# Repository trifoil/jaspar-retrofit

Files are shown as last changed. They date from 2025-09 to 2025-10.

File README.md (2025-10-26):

# jaspar-retrofit
Retrofit of Jaspar 1MVZ milling machine

## Components

| Quantity | Brand | Designation  |  Useful name  | Additional comments |
|:---|:---|:---|:-----|:-----|
|1| Schneider Electric | XB5AA25 |  Push button, Black |/|
|1| Schneider Electric | XB5AA15 |  Push button, White |/|
|1| Schneider Electric | XB5AA61 |  Push button, Blue |/|
|1| Schneider Electric | XB5AA55 |  Push button, Yellow |/|
|2| Schneider Electric | XB5AD33 | Selector switch | / |
|1| Schneider Electric | XB5PUSB3 |  Panel mounted USB 3.0 port | / |
|1| Schneider Electric | XB5AVB4 | Pilot light | / |

## Wiring 

### Operating principles

Once the main switch is turned on, the power is on for the computer, 24V alims and 

---

**Estop**

The E-stop has two contacts

* ZBE102 (red), Normally Closed, wired to a Mesa input     
* ZBE102 (red), Normally Closed, wired to the main safety relay     

When pressed, the circuit is open, as if there was no wire (that way if the estop wire is disconnected, the machine won't start):
* Software Estop is enabled
* The machine is on
* The relay is disabled, and the power contactors (X, Y, Z and Spindle) are open.
If the E-stop is disengaged, the circuit is closed and :
* Software Estop is disabled
* The machine is off
* The relay is enabled, and the power contactors (X, Y, Z and Spindle) are closed.

---

**Jog mode**

The MPG encoder is powered by 5V, linked to GND, and has 4 outputs but two are used : A+ and B+.

To override the normal operation of the machine one button is pressed, and enables the jog wheel while pressed.

The pin to enable jog is hm2_7i76e.0.7i76.0.0.input-20

Two selector buttons allow for selecting :

* The axis to move :
    * X
    * Y
    * Z
* The speed at which it is moving : 
    * X1
    * X10
    * X100

The card is in mode 2 to enable mpg inputs on these pins (sserial_port_0=20xxxxxx)

* The A+ signal is wired to hm2_7i76e.0.7i76.0.0.input-16
* The B+ signal is wired to hm2_7i76e.0.7i76.0.0.input-17

That way, the mpg input is readable on hm2_7i76e.0.7i76.0.0.enc0.count

For the axis selection : 

* hm2_7i76e.0.7i76.0.0.input-23
* hm2_7i76e.0.7i76.0.0.input-24
* if none is selected, Y is the axis to be selected

For the speed selection : 

* hm2_7i76e.0.7i76.0.0.input-21
* hm2_7i76e.0.7i76.0.0.input-22
* if none is selected, X10 is the axis to be selected

---

### Conventions

Convention for terminal blocks, where `X` is any number : 

| Designation  |  Useful name  |
|:---|:-----|
| 24v + | 24V+ |
| 24v gnd | 0V |
| 230v phase | P |
| 230v neutral | N |
| Coils | K`X` |
| Contact | K`X`.`X` |
| Switch | S |

### Mesa 7i76e jumpers

W2 and W3 are down, so the address of the card is 192.168.1.121 (default)

```sh
x@fedora:~$ ping 192.168.1.121
```

The answer should be : 
```txt
PING 192.168.1.121 (192.168.1.121) 56(84) bytes of data.
64 bytes from 192.168.1.121: icmp_seq=1 ttl=64 time=0.091 ms
64 bytes from 192.168.1.121: icmp_seq=2 ttl=64 time=0.109 ms
64 bytes from 192.168.1.121: icmp_seq=3 ttl=64 time=0.121 ms
```

### Mesa 7i76e wiring

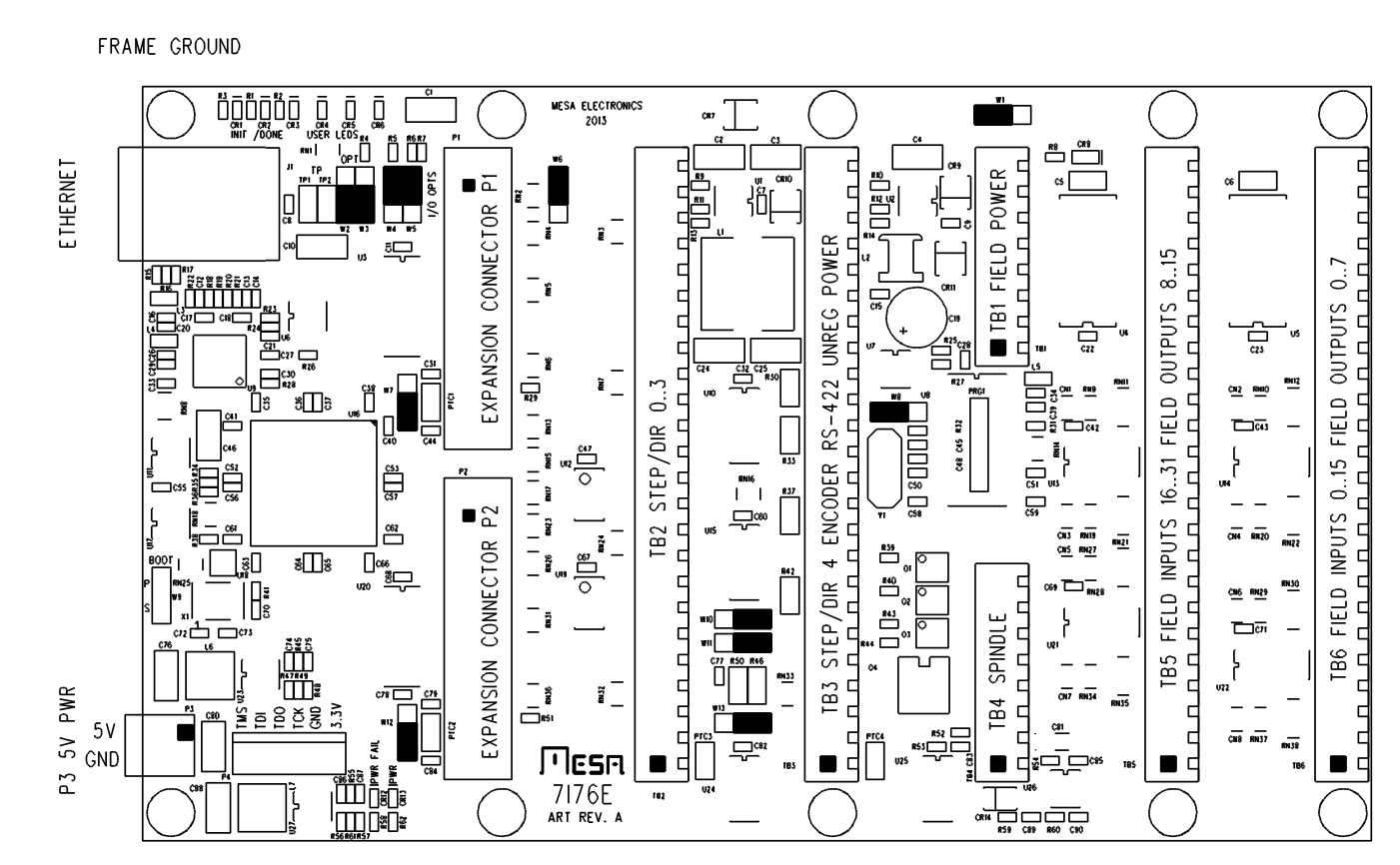
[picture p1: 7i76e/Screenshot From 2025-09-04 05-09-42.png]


Pins are numbered from bottom up.

0) **Power**

    | TB1 pin  |  Name   | Terminal block |
    |:---|:-----|:---|
    | 5 | VIN |  24V+  |     
    | 8 | GROUND |  0V  |     

    | TB3 pin  |  Name   | Terminal block |
    |:---|:-----|:---|
    | 22 | UNREG LOGIC PWR+ IN |  24V+  |     
    | 23 | GND |  0V  |    

1) **x Axis** 

    | TB2 pin  |  Name   |  Interface card pin  |
    |:---|:-----|:---|
    | 1 | GND |  /  |     
    | 2 |  STEP0-   | 41  |     
    | 3 |   STEP0+  |  43 |     
    | 4 |   DIR0-  |  37 |     
    | 5 |   DIR0+   | 39  |     
    | 6 |  +5VP   |  /  |     

2) **y Axis**

    | TB2 pin  |  Name   |  Interface card pin  |
    |:---|:-----|:---|
    | 7 | GND |  /  |     
    | 8 |  STEP1-   | 41  |     
    | 9 |   STEP1+  |  43 |     
    | 10 |   DIR1-  |  37 |     
    | 11 |   DIR1+   | 39  |     
    | 12 |  +5VP   |  /  |     

3) **z Axis**

    | TB2 pin  |  Name   |  Interface card pin  |
    |:---|:-----|:---|
    | 13 | GND |  /  |     
    | 14 |  STEP2-   | 41  |     
    | 15 |   STEP2+  |  43 |     
    | 16 |   DIR2-  |  37 |     
    | 17 |   DIR2+   | 39  |     
    | 18 |  +5VP   |  /  |     

4) **Spindle**

    | TB5 pin  |  Name   |  Relay coil  |
    |:---|:-----|:---|
    | 17 | OUTPUT8 |  C1  |     

5) **Jog MPG** (hm2_7i76e.0.7i76.0.0.enc0.count)

    | TB3 pin  |  Name   | MPG contact |
    |:---|:-----| :--- |
    | 9 | GND | GND |
    | 12 | +5VP | VCC |

    | TB5 pin  |  Name   | MPG contact |
    |:---|:-----| :--- |
    | 1 | INPUT16 | A+ |
    | / | / | A- |
    | 2 | INPUT17 | B+ |
    | / | / | B- |

6) **Jog enabling button**

    | TB5 pin  |  Name   | HAL name |
    |:---|:-----|:---|
    | 5 | INPUT20 | hm2_7i76e.0.7i76.0.0.input-20 |

7) **Speed selector button**

    | TB5 pin  |  Name   |  Position  |
    |:---|:-----|:---|
    | 6 | INPUT21 | X1 |
    | 7 | INPUT22 | X100 |

    If none is selected, the speed is X10

8) **Axis selector button**

    | TB5 pin  |  Name   |  Position  |
    |:---|:-----|:---|
    | 8 | INPUT23 | X |
    | 9 | INPUT24 | Z |

    If none is selected, the axis is Y

9) **Program start**

    | TB5 pin  |  Name   |  
    |:---|:-----|
    | 10 | INPUT25 | 

10) **Program pause**

    | TB5 pin  |  Name   |
    |:---|:-----|
    | 11 | INPUT26 |

11) **Estop**

    | TB5 pin  |  Name   |
    |:---|:-----|
    | 12 | INPUT27 |

12) **Coolant**

    | TB5 pin  |  Name   |
    |:---|:-----|
    | 13 | INPUT28 |

13) **Limit switches**

    | TB6 pin  |  Name   | Axis |
    |:---|:-----|:---|
    | 1 | INPUT0 | X |
    | 2 | INPUT1 | Y |
    | 3 | INPUT2 | Z |

14) **Homing sensor**

    | TB6 pin  |  Name   | Axis |
    |:---|:-----|:---|
    | 4 | INPUT3 | X |
    | 5 | INPUT4 | Y |
    | 6 | INPUT5 | Z |

15) **Z axis brake**

    | TB5 pin  |  Name   |
    |:---|:-----|
    | 18 | OUTPUT9 |

## Important notes 

In order to select the mode 2 of the mesa 7i76e board, this line 

```hal
loadrt hm2_eth board_ip="192.168.1.121" config="num_encoders=1 num_pwmgens=0 num_stepgens=5 sserial_port_0=00xxxxxx" 
```

has to be changed to this

```hal
loadrt hm2_eth board_ip="192.168.1.121" config="num_encoders=1 num_pwmgens=0 num_stepgens=5 sserial_port_0=20xxxxxx" 
```

The pc is connected with : 
* ip:192.168.1.3 
* gateway:192.168.1.254 
* mask: 255.255.255.0

## QTPYVCP interface

```sh
sudo apt update -y
sudo apt upgrade -y

sudo apt install curl -y
echo 'deb [arch=amd64] https://repository.qtpyvcp.com/apt stable main' | sudo tee /etc/apt/sources.list.d/kcjengr.list
curl -sS https://repository.qtpyvcp.com/repo/kcjengr.key | gpg --dearmor | sudo tee /etc/apt/trusted.gpg.d/kcjengr.gpg
gpg --keyserver keys.openpgp.org --recv-key 2DEC041F290DF85A
sudo apt update -y

sudo apt install python3-qtpyvcp -y
sudo apt install python3-probe-basic -y
sudo apt install python3-monokrom -y 
sudo apt install python3-turbonc -y

```

## Sources

https://www.qtpyvcp.com/index.html

## Notes

I have one homing inductive sensor per axis

I have two limit switches per axis (that trip the physical estop) 

I want my machine to have a homing performed when I switch it on.

Estop off -> machine enabled -> axis moving a bit in the opposite direction of the home -> axis moving back until the home proximity sensor trips -> axis are zeroed

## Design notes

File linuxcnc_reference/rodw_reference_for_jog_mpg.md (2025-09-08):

But back onto LinuxCNC, I promised I'd show document how I got an MPG running on the 7i76e. Lets start with the scale selector. I knew I need a 2 bit binary output but I've only ever made them in software before so I asked a friend what to get and he said to get one of these from Jaycar . That looked right to me so I grabbed one as I was close to one of their shops.

There were 3 outputs in the centre of the switch (A, B & C). We only need two of these so I picked A & B. But it really did my head in trying to work out how to use it in the absence of documentation. After a while with a multimeter I worked out which wire went where but I still could not work it out. Then I decided I needed to build a truth table showing the binary logic required:

 Pos   A B
  0:   0 0
  1:   0 1
  2:   1 0
  3:   1 1

And work out what wires were required to be live where ever there was a 1. My switch pinout said I needed to make pins 3, 4, 6 and 8 live so I tied them together with a yellow wire attached to +24v and an orange and green wire on the centre inputs going to the mux4 pins.

File Attachment:

File Attachment:

I made a bracket for the 100PPR encoder wheel from some scrap angle iron so it would not short out
File Attachment:

The wiring was pretty simple

I stole some 5 volt power from one of the stepper power pins.
Encode A connects to TB3.16
Encoder B connects to TB3.17

I did run into trouble until I found a post from PCW which said if you are using a separate 5V power supply like I am, you needed to tie the 24 volt and 5 volt pin Grounds together. Eg. Connect TB1.1 to TB2.23. But if you follow this wiring schematic , you won't need to do this

As the 7i76e has 2 encoder inputs, I figured I'd use separate encoders for the X & Y axis.

Some of the examples I had seen used the -not signal from an unused input for the encoder enable inut but this looked a bit dodgy to me. Why not simply OR the 2 encoder input pins together and use the output from that as the enable signal? By doing that , the encode will be disabled when the scale switch is at position 0 and enabled at any of the scale settings. Nice and clean!

Here is what the HAL file looks like:

```hal
# Metric units used
loadrt hm2_eth board_ip="10.10.10.10" config="firmware=hm2/7i76/7i76e.BIT num_encoders=1 num_pwmgens=0 num_stepgens=5  sserial_port_0=2xxxx" 

loadrt mux4 count=1
addf mux4.0 servo-thread
loadrt or2 count=4
addf or2.3  servo-thread

setp axis.x.jog-vel-mode 0
net x-jog-counter <=  hm2_7i76e.0.7i76.0.0.enc0.count
net x-jog-counter => axis.x.jog-counts
net mux-in1 or2.3.in0 <= hm2_7i76e.0.7i76.0.0.input-22 => mux4.0.sel0
net mux-in2 or2.3.in1 <= hm2_7i76e.0.7i76.0.0.input-21 => mux4.0.sel1
net x-jog-enable <= or2.3.out
net x-jog-enable => axis.x.jog-enable
setp mux4.0.in0 0.0
setp mux4.0.in1 1.0
setp mux4.0.in2 0.1
setp mux4.0.in3 0.01
net x-jog-scale mux4.0.out => axis.x.jog-scale
```

This is set up for a metric machine and the scale is 1mm, 0.1mm and 0.01mm. If you find the scale is reversed, it is becasue the pins are mapped in the reverse order. (eg low order pin connected to high order bit). If this happens to you, just edit the pins in this code.
```hal
net mux-in1 or2.3.in0 <= hm2_7i76e.0.7i76.0.0.input-22 => mux4.0.sel0
net mux-in2 or2.3.in1 <= hm2_7i76e.0.7i76.0.0.input-21 => mux4.0.sel1
```

Remember to change this line based on your config. I had already used a few or2's
```hal
loadrt or2 count=4
```
Well, thats about it for now. The shopping list is becoming very short.
1. 9 core shielded wire for the connection to the plasma power supply now the connector is to hand
2. A 3 stage air filter including a desiccant drier stage I've had my eye on.
3. About 10 metres of 100 x 100 x 5mm SHS for the frame and some other sundry steel.

The main things I have to do in HAL are:
1. All the THC stuff
2. Sort out my stepper drives so they are working on the correct axis
3. Implement Gantry Joint Axis .
4. Get my warning lights working the way I want them to and I'll need some help on that one.

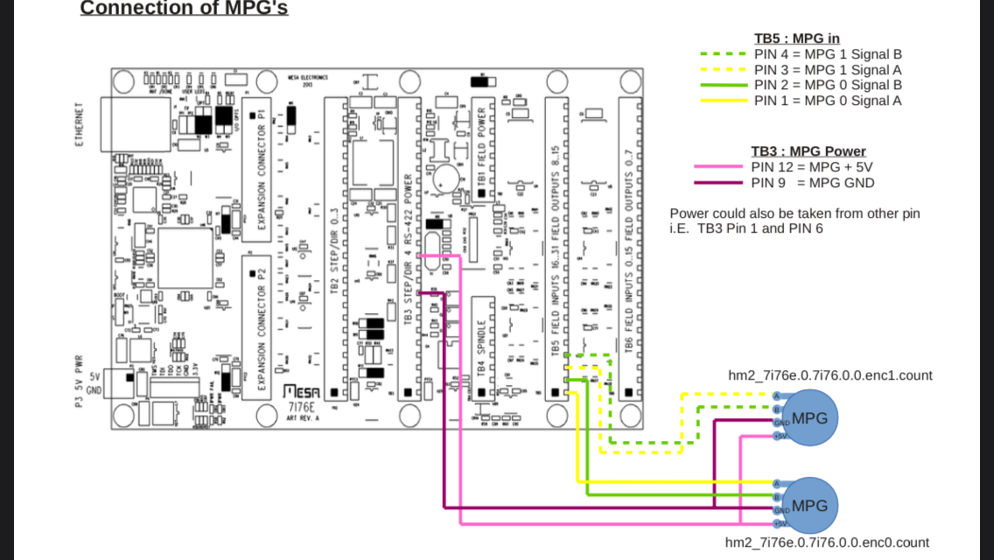
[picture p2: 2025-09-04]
Pasted image (2).png

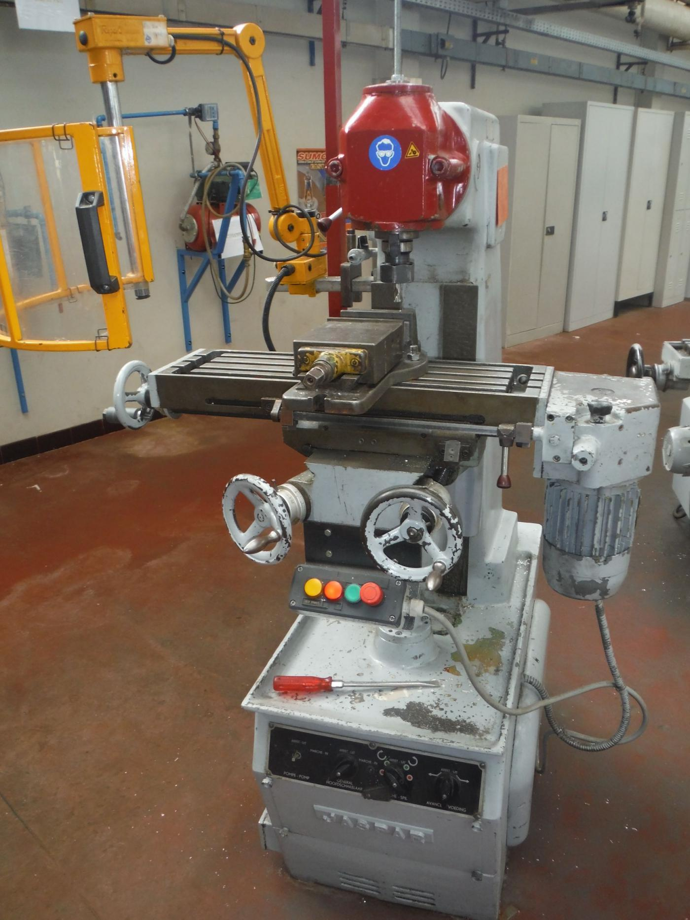
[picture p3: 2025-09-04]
Pasted image.png

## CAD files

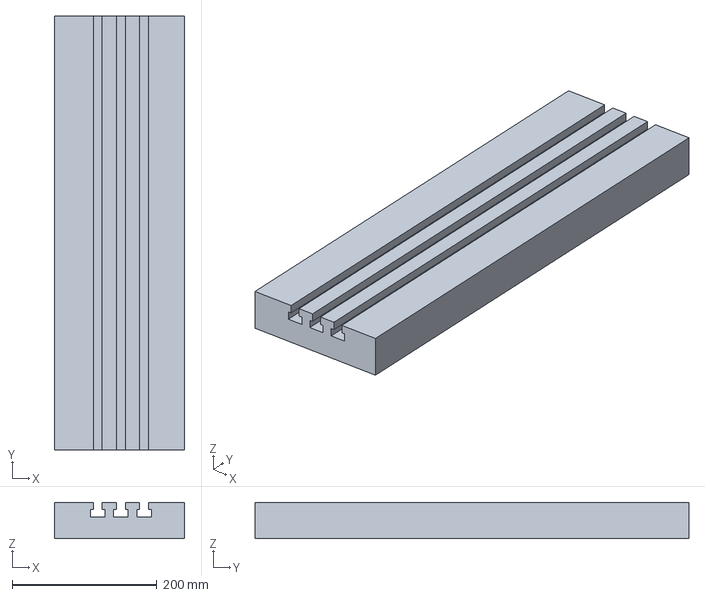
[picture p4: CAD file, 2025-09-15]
3d_models/JASPAR_6_0_0_table.FCStd
180.0 x 600.0 x 50.0 mm

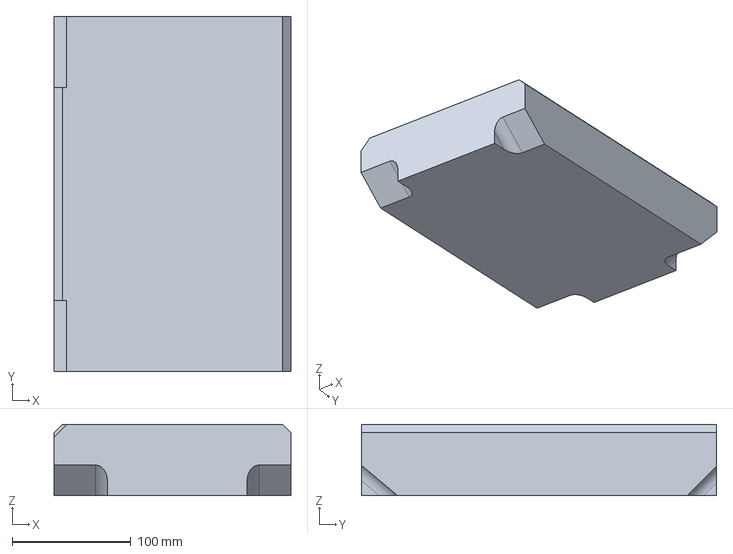
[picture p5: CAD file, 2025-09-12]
3d_models/JASPAR_5_0_0_mid.FCStd
200.0 x 300.0 x 60.0 mm

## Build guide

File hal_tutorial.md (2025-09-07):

# HAL

Hal stands for ```hardware abstraction layer```

Assembles blocks to work together

At first it was only for hardware devices

## Principles

* Any system consists of interconnected components.
* The machine builder must select, mount and wire these pieces together to make a complete system.

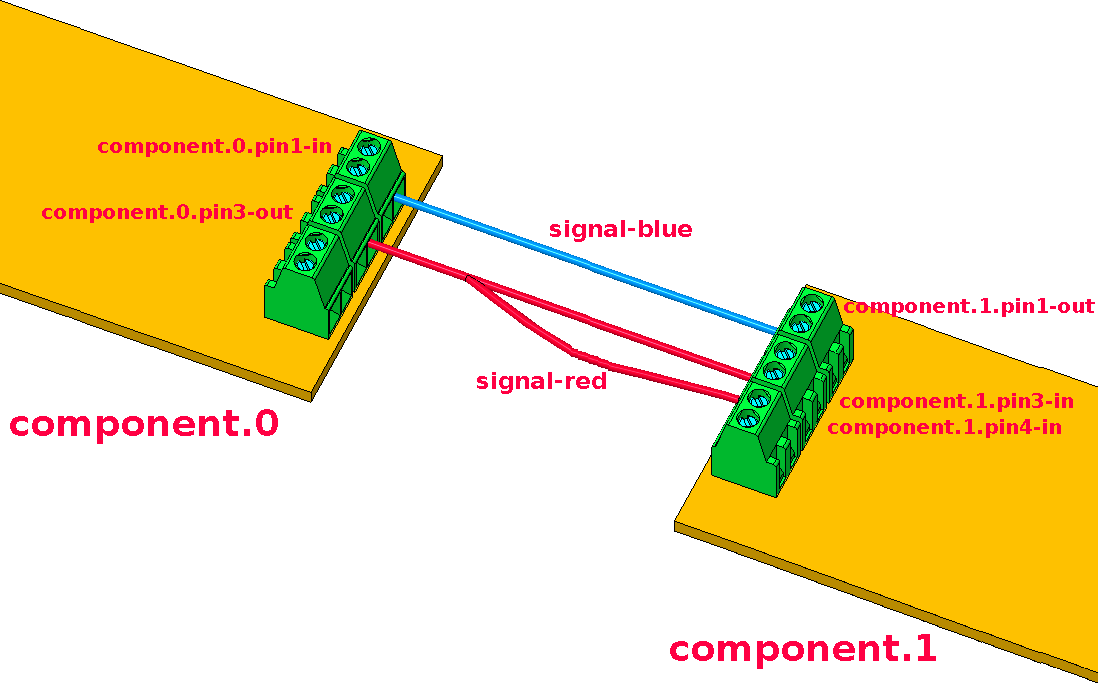
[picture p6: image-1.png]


translates to :

```txt
net signal-blue    component.0.pin1-in      component.1.pin1-out
net signal-red     component.0.pin3-out     component.1.pin3-in     component.1.pin4-in
```

### Part selection

* The machine builder treats each individual part as black boxes.
* In the HAL world, the integrator must decide what HAL components are needed. 
* Usually every interface card will require a driver. 
* Additional components may be needed for software generation of step pulses, PLC functionality, and a wide variety of other tasks.

### Interconnecting

* When using HAL, components are interconnected by signals. 
* The designer must decide which signals are needed, and what they should connect.

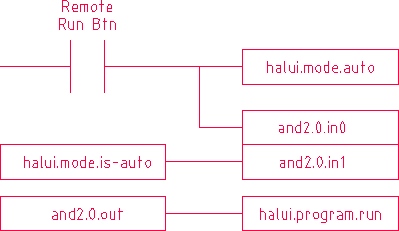
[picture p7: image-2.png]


# Estop

```hal
# --- Load the necessary components ---
# Load the driver for your I/O card (7i96 in this example)
loadrt hm2_eth board_ip="192.168.1.121" config="num_encoders=0 num_stepgens=5"
loadrt threads name1=servo-thread period1=1000000 # 1ms thread

# Load a simple logic component (NOT gate)
loadrt not count=1

# --- Wire the physical input to the HAL ---
# Connect the physical pin "INPUT18" to a HAL pin named "estop_physical"
net estop-physical-in hm2_7i96.0.7i96.gpio.055.in-18 => not.0.in

# --- Apply the necessary logic ---
# The physical input is ACTIVE LOW (FALSE when pressed).
# We need to INVERT it to get an ESTOP signal that is TRUE when active.
net estop-active not.0.out => iocontrol.0.emc-enable-in

# --- Add the components to a thread so they run ---
addf not.0 servo-thread
addf hm2_7i96.0.read servo-thread
addf hm2_7i96.0.write servo-thread
```

How it works:

* The physical E-Stop button is wired to INPUT18.

* The hm2_7i96 driver reads this pin and sets the value of its HAL pin hm2_7i96.0.7i96.gpio.055.in-18.

* The net command connects this physical pin to the input of a not component.

* The not component inverts the signal:

    * E-Stop NOT pressed (circuit closed): in-18 is TRUE -> not.out is FALSE

    * E-Stop IS pressed (circuit open): in-18 is FALSE -> not.out is TRUE

* This inverted signal (estop-active) is then connected to iocontrol.0.emc-enable-in. This pin expects TRUE to enable the machine and FALSE to disable it. Our logic now correctly disables the machine when the E-Stop is pressed.

## NOT

Right now your E-Stop is wired as normally closed (NC), so you’re inverting the signal with not.0.
If you’re changing it to normally open (NO) — meaning 1 = pressed / fault, 0 = OK — then you no longer need the not component.

Here’s how you can modify your HAL file:

Remove these lines:

loadrt not
addf not.0 servo-thread
net estop-in     => not.0.in
net estop-fault  <= not.0.out
net estop-fault    => iocontrol.0.emc-enable-in

Replace with a direct connection:
# --- Physical E-stop on INPUT18 ---
# Normally open: 0 = OK, 1 = E-stop pressed

net estop-in    <=  hm2_7i76e.0.7i76.0.0.input-18
net estop-in    =>  iocontrol.0.emc-enable-in
This way, the signal from your Mesa input goes directly to LinuxCNC’s iocontrol.0.emc-enable-in, no inversion needed.

⚠️ Before running the machine, test with halmeter or halscope:

E-Stop released → signal = 0 (OK)

E-Stop pressed → signal = 1 (Triggers E-Stop)

Do you also want me to adjust comments in the HAL file so it’s clear it’s now NO wiring instead of NC?

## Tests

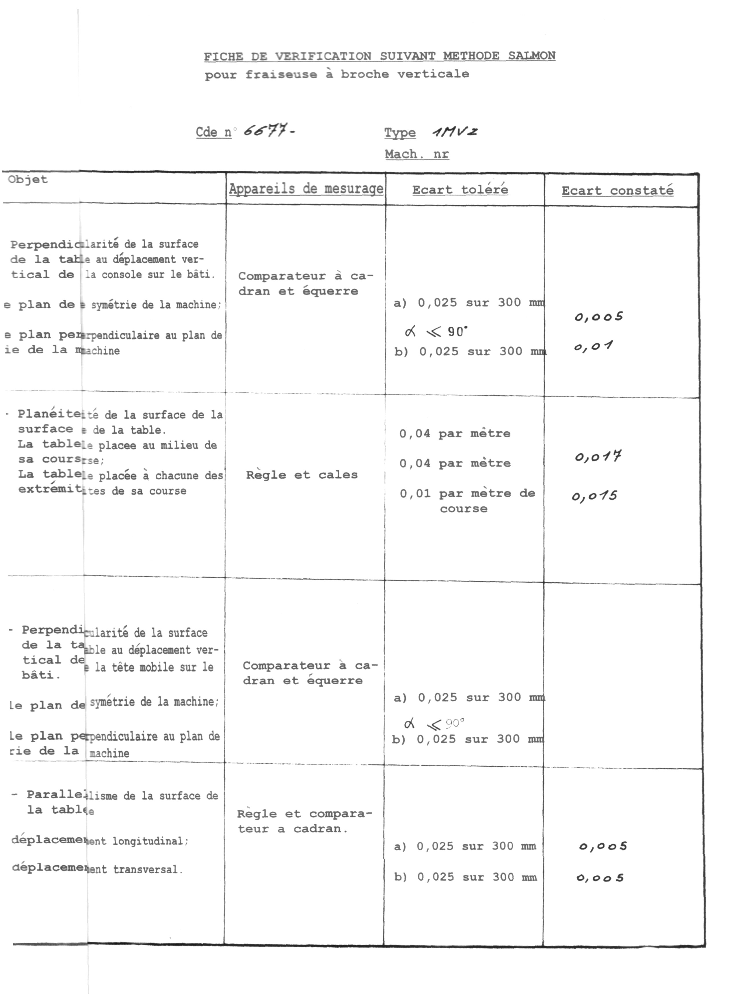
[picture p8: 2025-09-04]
Jaspar 1MVZ Handleiding-v2/1MVZ-Verificatie-1b.jpg

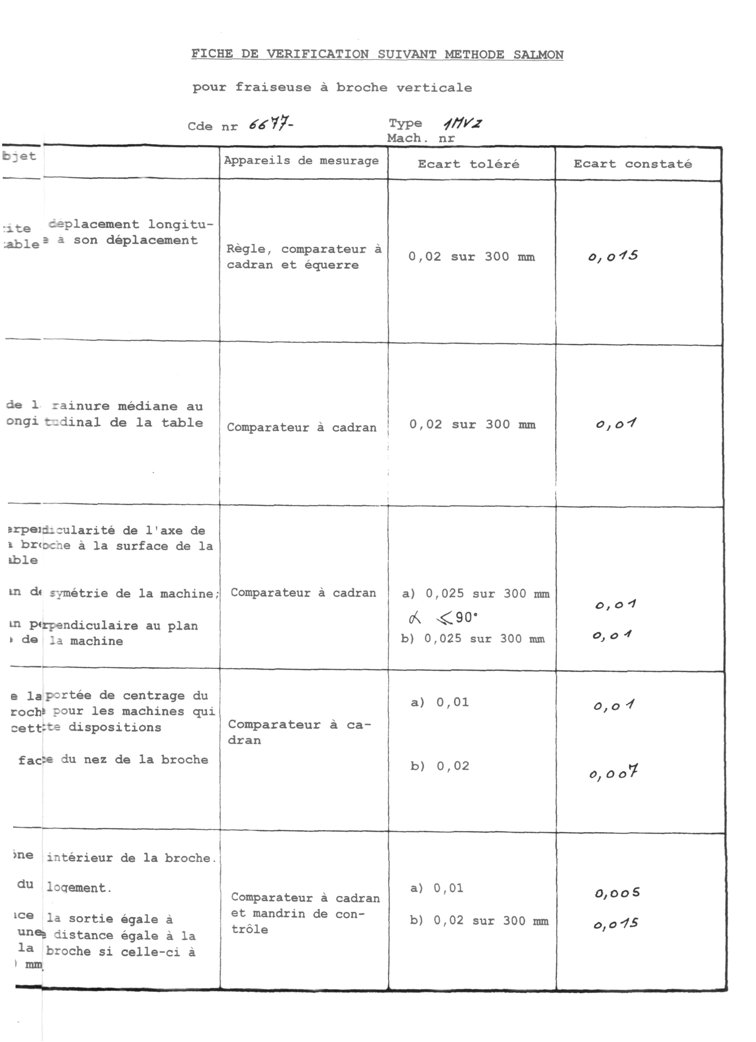
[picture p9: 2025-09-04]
Jaspar 1MVZ Handleiding-v2/1MVZ-Verificatie-2b.jpg

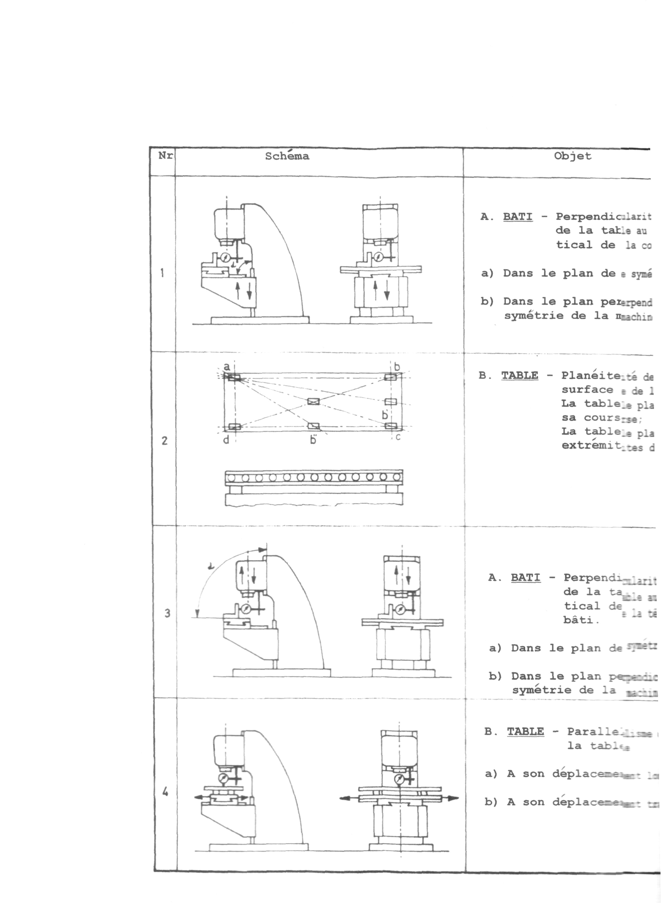
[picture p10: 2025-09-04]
Jaspar 1MVZ Handleiding-v2/1MVZ-Verificatie-1a.jpg

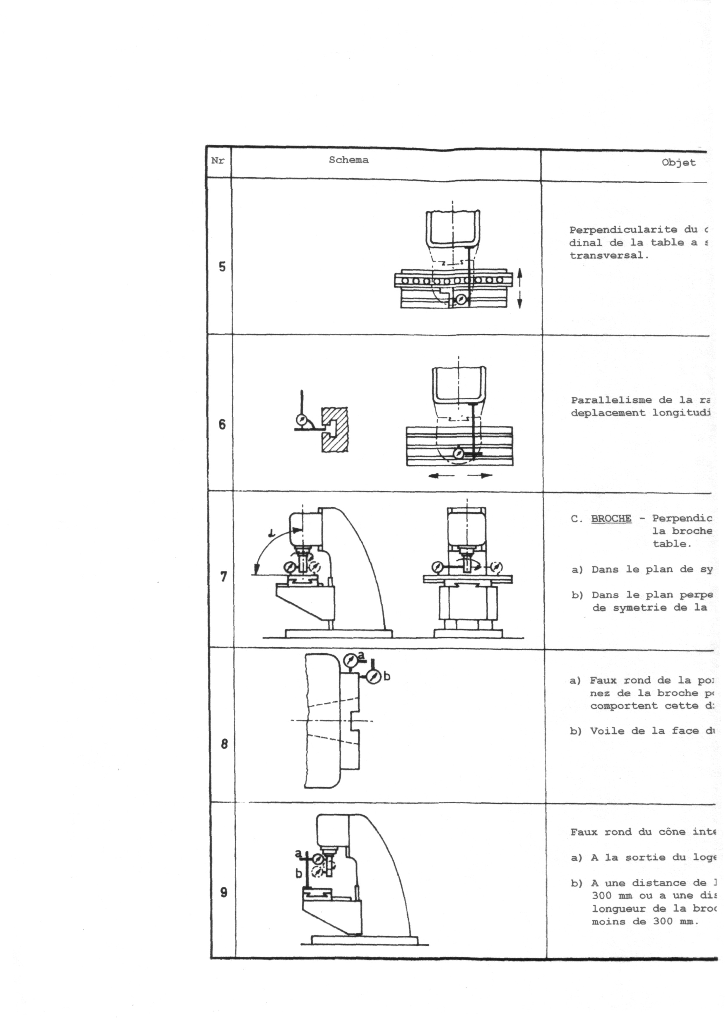
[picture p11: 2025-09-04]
Jaspar 1MVZ Handleiding-v2/1MVZ-Verificatie-2a.jpg

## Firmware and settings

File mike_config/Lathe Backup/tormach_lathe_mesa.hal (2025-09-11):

# Tormach Lathe Hal file for Mesa 5i25 and 7i92

# load RT components
loadrt trivkins
loadusr -W hwmon $INI_FILE_NAME
loadrt [EMCMOT]EMCMOT servo_period_nsec=[EMCMOT]SERVO_PERIOD num_joints=[TRAJ]AXES num_dio=64
loadrt hostmot2
loadrt [HOSTMOT2]DRIVER [HOSTMOT2]DRIVER_PARAMS
loadrt estop_latch
loadrt tormachltc
#loadrt near
loadrt gearchange count=1
loadrt not names=prog-not-idle
loadrt machineokdb names=machine-ok-db
loadrt and2 names=stepper-drive-trip,probe-enable-input 
loadrt ilowpass count=2
loadrt tormachcolletcontrol

# Load the mux4 and two or2's for mpgs
loadrt or2 names=enable-limits,or-mux-in0,or-mux-in1
loadrt mux4 names=mux-axis-scale
loadusr -Wn usbio usbio.py -n usbio





# as per Peter Wallace to reduce encoder errors from noise
# use the 'raw' interface to set the encoder filter higher to ignore more noise
# this sets how long an encoder signal needs to be stable to be accepted
# register 0x3400 is QfilterRate decimal 13312
# count rate is ClockLow/(QfilterRate + 2)
# ClockLow is 33 MHz
# setting the filter to 38 (decimal) will allow the encoder to function well past 100 kHz
# lathe encoder is 1200 pulses per rev, 3000 RPM is 60 kHz
#
# TODO: FIX ME!!!!!
#setp hm2_[HOSTMOT2](BOARD).0.raw.write_address 13312
#setp hm2_[HOSTMOT2](BOARD).0.raw.write_data [SPINDLE]ENCODER_FILTER
#setp hm2_[HOSTMOT2](BOARD).0.raw.write_strobe TRUE

# stabilizes spindle RPM display
loadrt lowpass
setp lowpass.0.gain 0.01

# debounce - coolant relay switching noise hammers estop input
loadrt debounce cfg=1,3

# lut5.0 looks to be limit switch related
# lut5.1 handles collet closer control
loadrt lut5 count=2

# probe active high or low
loadrt xor2 names=probe-active-hi-lo




# used to decode the signal from the lathe control board that encodes
# the door and limit switches as a frequency
#loadrt freq2pin personality=0x0004
#setp freq2pin.0.freq-width 200
#setp freq2pin.0.input 0
#setp freq2pin.0.stability-count 25
#setp freq2pin.0.stability-width 20
#setp freq2pin.0.freq-table-00 1800
#setp freq2pin.0.freq-table-01 2000
#setp freq2pin.0.freq-table-02 2200
#setp freq2pin.0.freq-table-03 2400
#setp freq2pin.0.freq-table-04 2600
#setp freq2pin.0.freq-table-05 2800
#setp freq2pin.0.freq-table-06 3000
#setp freq2pin.0.freq-table-07 3200
#setp freq2pin.0.freq-table-08 3400
#setp freq2pin.0.freq-table-09 3600
#setp freq2pin.0.freq-table-10 3800
#setp freq2pin.0.freq-table-11 4000
#setp freq2pin.0.freq-table-12 4200
#setp freq2pin.0.freq-table-13 4400
#setp freq2pin.0.freq-table-14 4600
#setp freq2pin.0.freq-table-15 4800

#############################################################################
# servo thread
#
# mesa card .read should be the first thing added to the servo-thread
# where .write should be the last thing added. that way everything
# gets the freshest data from .read and .write sets all the new output data
#
addf hm2_[HOSTMOT2](BOARD).0.read servo-thread

#addf freq2pin.0 servo-thread


addf lut5.0 servo-thread
addf lut5.1 servo-thread
addf debounce.0 servo-thread
addf debounce.1 servo-thread
addf probe-active-hi-lo servo-thread
addf probe-enable-input servo-thread
addf enable-limits servo-thread
addf stepper-drive-trip servo-thread

# Add the components to the servo-thread
addf mux-axis-scale servo-thread
addf or-mux-in0     servo-thread
addf or-mux-in1     servo-thread
addf ilowpass.0     servo-thread
addf ilowpass.1     servo-thread




########################################################################
# noise debounce for estop
# debounce.0 no longer used but left installed for the time being
# temporarily bump from 150 ms to 850 ms to debug seemingly random e-stops
#setp debounce.0.delay 850
###### estop debounce

addf machine-ok-db servo-thread
setp machine-ok-db.delay 850

# limit and door switches and probe/accessory input
setp debounce.1.delay 10

addf lowpass.0 servo-thread

# always needed
addf motion-command-handler servo-thread
addf motion-controller servo-thread

addf estop-latch.0 servo-thread

# used by spindle speed
addf gearchange.0 servo-thread
#addf near.0 servo-thread

addf tormachltc.0 servo-thread

addf prog-not-idle servo-thread

addf tormachcolletcontrol.0 servo-thread

# .write should be last after new outputs are computed
# in servo-thread

addf hm2_[HOSTMOT2](BOARD).0.write servo-thread



###############################################################
# 5i25 watchdog timeout
# 10 milliseconds (~10 times the servo loop period)
setp hm2_[HOSTMOT2](BOARD).0.watchdog.timeout_ns 10000000


###############################################################
# 5i25
# Configuration pin-out:

### hm2_[HOSTMOT2](BOARD).0.gpio.016.in Encoder-phase-A
### hm2_[HOSTMOT2](BOARD).0.gpio.015.in Encoder-phase-B
### hm2_[HOSTMOT2](BOARD).0.gpio.014.in_not Encoder-phase-Z

#
#    IO Connections For 7i76

#	TB6 Pin    	INPUT Pins
#	1    		0-INPUT		Stepper Drive Trip
#    	2		1-INPUT		Stepper Drive Trip
#    	3		2-INPUT       
#    	4		3-INPUT 	Door Switch      
#    	5		4-INPUT		Z Limit Switch       
#    	6		5-INPUT		X Limit Switch       
#    	7		6-INPUT      
#    	8		7-INPUT		Probe Input      
#    	9		8-INPUT 
#	10		9-INPUT		
      
#    TB6 Pin 		Output Pins         
#    	17		0-Output	Spindle Forward Relay       
#    	18		1-Output	Spindle Reverse Relay       
#    	19		2-Output	Flood Coolant
#    	20		3-Output      	Mist Coolant
#    	21		4-Output  
#    	22		5-Output    	VFD Enable Relay 
#    	23		6-Output       
#    	24		7-Output	STOP Output Pin   


#    TB5 Pin 		Output Pins  
#    	17		8-Output    
#    	18		9-Output
#    	19		10-Output
#    	20		11-Output
#    	21		12-Output
#    	22		13-Output
#   	23	 	14-Output 	Enable Limits Output Pin
#	24		15-Output


# 	TB2		Signal Pins
#	1		GND
#	2		Step0-
#	3		Step0+
#	4		Dir0-
#	5		Dir0+
#	6		+5V
#	7		GND
#	8		Step1-
#	9		Step1+
#	10		Dir1-
#	11		Dir1+
#	12		+5V
#	13		GND
#	14		Step2-
#	15		Step2+
#	16		Dir2-
#	17		Dir2+
#	18		+5V
#	19		GND
#	20		Step3-
#	21		Step3+
#	22		Dir3-
#	23		Dir3+
#	24		+5V


# 	TB3		Signal Pins
#	1		GND
#	2		Step4-
#	3		Step4+
#	4		Dir4-
#	5		Dir4+
#	6		+5V
#	7		ENCA+
#	8		ENCA-
#	9		GND
#	10		ENCB+
#	11		ENCB-
#	12		GND
#	13		+5V
#	14		IDX+
#	15		IDX-
#	16		
#	17		
#	18		
#	19		
#	20		+5V
#	21		+5V
#	22		+5V
#	23		GND
#	24		GND

#############################################################################
# Load Comp for Arduino Mega Controlled I/0 copy to folder below
# sudo cp arduino-connector.py /home/operator/v2.9.2/bin/arduino-connector

#loadusr arduino-connector 

#############################################################################



########################################################################
# DPLL configuration
#setp hm2_[HOSTMOT2](BOARD).0.dpll.01.timer-us [HOSTMOT2](DPLL_TIMER_US)

# default is -1 which means don't use the DPLL timer and simply sample on read()
# set to 1 for Ethernet boards to use DPLL timer 1 and sample 100 micro seconds
# before the nominal servo thread read() time
#setp hm2_[HOSTMOT2](BOARD).0.stepgen.timer-number  [HOSTMOT2](DPLL_TIMER_NUMBER)
#setp hm2_[HOSTMOT2](BOARD).0.encoder.timer-number  [HOSTMOT2](DPLL_TIMER_NUMBER)

###############################################################
# Spindle speed controlled by frequency
#
# LinuxCNC (rpm) => gearchange (pulse-freq) => stepgen (step & dir) => spindle
#

setp gearchange.0.min1 [SPINDLE]LO_RANGE_MIN
setp gearchange.0.max1 [SPINDLE]LO_RANGE_MAX
setp gearchange.0.min2 [SPINDLE]HI_RANGE_MIN
setp gearchange.0.max2 [SPINDLE]HI_RANGE_MAX
setp gearchange.0.scale2 [SPINDLE]HI_RANGE_SCALE
setp gearchange.0.sel 1
net spindle-range            gearchange.0.sel
net spindle-range-alarm      gearchange.0.alarm

# direction not controlled via gearchanger, so reverse isn't set
# and the dir-in and dir-out pins aren't linked

net spindle-speed-raw motion.spindle-speed-out gearchange.0.speed-in
net spindle-speed gearchange.0.speed-out hm2_[HOSTMOT2](BOARD).0.stepgen.01.velocity-cmd

# type 1 velocity control mode
setp hm2_[HOSTMOT2](BOARD).0.stepgen.01.control-type 1

# step/dir
# type 2 quadrature output for 50% duty cycle
setp hm2_[HOSTMOT2](BOARD).0.stepgen.01.step_type 2

# position = counts / position_scale
# this scales the input RPM to the output frequency
# fast spindle pulley 1000 Hz -> 1000 RPM
setp hm2_[HOSTMOT2](BOARD).0.stepgen.01.position-scale [SPINDLE]LO_SCALE

# no limit on acceleration
setp hm2_[HOSTMOT2](BOARD).0.stepgen.01.maxaccel 0

# for lathe 5000 Hz/RPM max
# 000 Hz maximum frequency, position units / second
setp hm2_[HOSTMOT2](BOARD).0.stepgen.01.maxvel 2000

# stepspace in nanoseconds
setp hm2_[HOSTMOT2](BOARD).0.stepgen.01.stepspace 0

# steplen 10 Micro Seconds
setp hm2_[HOSTMOT2](BOARD).0.stepgen.01.steplen 10000

# Spindle run assigned in the the POSTGUI_HALFILE
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

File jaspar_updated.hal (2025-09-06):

# Jaspar 1MVZ Milling Machine HAL Configuration - Updated
# Using Mesa 7i76e Ethernet card
# Based on current PNCconf structure with Jaspar customizations

# Generated by PNCconf at Sat Sep  6 04:06:15 2025
# Using LinuxCNC version:  Master (2.9)

loadrt [KINS]KINEMATICS
loadrt [EMCMOT]EMCMOT servo_period_nsec=[EMCMOT]SERVO_PERIOD num_joints=[KINS]JOINTS
loadrt hostmot2
loadrt hm2_eth board_ip="192.168.1.121" config="num_encoders=1 num_pwmgens=0 num_stepgens=3 sserial_port_0=00xxxxxx" 
setp    hm2_7i76e.0.watchdog.timeout_ns 5000000

# Jaspar custom components
loadrt pid names=pid.x,pid.y,pid.z
loadrt encoder names=mpg-encoder
loadrt mux4 names=mpg-mux
loadrt scale names=mpg-scale

addf hm2_7i76e.0.read          servo-thread
addf motion-command-handler   servo-thread
addf motion-controller        servo-thread
addf pid.x.do-pid-calcs       servo-thread
addf pid.y.do-pid-calcs       servo-thread
addf pid.z.do-pid-calcs       servo-thread
# Jaspar custom thread additions
addf mpg-encoder               servo-thread
addf mpg-mux                   servo-thread
addf mpg-scale                 servo-thread
addf hm2_7i76e.0.write         servo-thread
setp hm2_7i76e.0.dpll.01.timer-us -50
setp hm2_7i76e.0.stepgen.timer-number 1

# external output signals
# external input signals

#*******************
#  AXIS X JOINT 0
#*******************

setp   pid.x.Pgain     [JOINT_0]P
setp   pid.x.Igain     [JOINT_0]I
setp   pid.x.Dgain     [JOINT_0]D
setp   pid.x.bias      [JOINT_0]BIAS
setp   pid.x.FF0       [JOINT_0]FF0
setp   pid.x.FF1       [JOINT_0]FF1
setp   pid.x.FF2       [JOINT_0]FF2
setp   pid.x.deadband  [JOINT_0]DEADBAND
setp   pid.x.maxoutput [JOINT_0]MAX_OUTPUT
setp   pid.x.error-previous-target true
setp   pid.x.maxerror 0.012700

net x-index-enable  =>  pid.x.index-enable
net x-enable        =>  pid.x.enable
net x-pos-cmd       =>  pid.x.command
net x-pos-fb        =>  pid.x.feedback
net x-output        <=  pid.x.output

# Step Gen signals/setup
setp   hm2_7i76e.0.stepgen.00.dirsetup        [JOINT_0]DIRSETUP
setp   hm2_7i76e.0.stepgen.00.dirhold         [JOINT_0]DIRHOLD
setp   hm2_7i76e.0.stepgen.00.steplen         [JOINT_0]STEPLEN
setp   hm2_7i76e.0.stepgen.00.stepspace       [JOINT_0]STEPSPACE
setp   hm2_7i76e.0.stepgen.00.position-scale  [JOINT_0]STEP_SCALE
setp   hm2_7i76e.0.stepgen.00.step_type        0
setp   hm2_7i76e.0.stepgen.00.control-type     1
setp   hm2_7i76e.0.stepgen.00.maxaccel         [JOINT_0]STEPGEN_MAXACCEL
setp   hm2_7i76e.0.stepgen.00.maxvel           [JOINT_0]STEPGEN_MAXVEL

# ---closedloop stepper signals---
net x-pos-cmd    <= joint.0.motor-pos-cmd
net x-vel-cmd    <= joint.0.vel-cmd
net x-output     => hm2_7i76e.0.stepgen.00.velocity-cmd
net x-pos-fb     <= hm2_7i76e.0.stepgen.00.position-fb
net x-pos-fb     => joint.0.motor-pos-fb
net x-enable     <= joint.0.amp-enable-out
net x-enable     => hm2_7i76e.0.stepgen.00.enable

# ---setup home / limit switch signals---
net x-home-sw     =>  joint.0.home-sw-in
net x-neg-limit     =>  joint.0.neg-lim-sw-in
net x-pos-limit     =>  joint.0.pos-lim-sw-in

#*******************
#  AXIS Y JOINT 1
#*******************

setp   pid.y.Pgain     [JOINT_1]P
setp   pid.y.Igain     [JOINT_1]I
setp   pid.y.Dgain     [JOINT_1]D
setp   pid.y.bias      [JOINT_1]BIAS
setp   pid.y.FF0       [JOINT_1]FF0
setp   pid.y.FF1       [JOINT_1]FF1
setp   pid.y.FF2       [JOINT_1]FF2
setp   pid.y.deadband  [JOINT_1]DEADBAND
setp   pid.y.maxoutput [JOINT_1]MAX_OUTPUT
setp   pid.y.error-previous-target true
setp   pid.y.maxerror 0.012700

net y-index-enable  =>  pid.y.index-enable
net y-enable        =>  pid.y.enable
net y-pos-cmd       =>  pid.y.command
net y-pos-fb        =>  pid.y.feedback
net y-output        <=  pid.y.output

# Step Gen signals/setup
setp   hm2_7i76e.0.stepgen.01.dirsetup        [JOINT_1]DIRSETUP
setp   hm2_7i76e.0.stepgen.01.dirhold         [JOINT_1]DIRHOLD
setp   hm2_7i76e.0.stepgen.01.steplen         [JOINT_1]STEPLEN
setp   hm2_7i76e.0.stepgen.01.stepspace       [JOINT_1]STEPSPACE
setp   hm2_7i76e.0.stepgen.01.position-scale  [JOINT_1]STEP_SCALE
setp   hm2_7i76e.0.stepgen.01.step_type        0
setp   hm2_7i76e.0.stepgen.01.control-type     1
setp   hm2_7i76e.0.stepgen.01.maxaccel         [JOINT_1]STEPGEN_MAXACCEL
setp   hm2_7i76e.0.stepgen.01.maxvel           [JOINT_1]STEPGEN_MAXVEL

# ---closedloop stepper signals---
net y-pos-cmd    <= joint.1.motor-pos-cmd
net y-vel-cmd    <= joint.1.vel-cmd
net y-output     => hm2_7i76e.0.stepgen.01.velocity-cmd
net y-pos-fb     <= hm2_7i76e.0.stepgen.01.position-fb
net y-pos-fb     => joint.1.motor-pos-fb
net y-enable     <= joint.1.amp-enable-out
net y-enable     => hm2_7i76e.0.stepgen.01.enable

# ---setup home / limit switch signals---
net y-home-sw     =>  joint.1.home-sw-in
net y-neg-limit     =>  joint.1.neg-lim-sw-in
net y-pos-limit     =>  joint.1.pos-lim-sw-in

#*******************
#  AXIS Z JOINT 2
#*******************

setp   pid.z.Pgain     [JOINT_2]P
setp   pid.z.Igain     [JOINT_2]I
setp   pid.z.Dgain     [JOINT_2]D
setp   pid.z.bias      [JOINT_2]BIAS
setp   pid.z.FF0       [JOINT_2]FF0
setp   pid.z.FF1       [JOINT_2]FF1
setp   pid.z.FF2       [JOINT_2]FF2
setp   pid.z.deadband  [JOINT_2]DEADBAND
setp   pid.z.maxoutput [JOINT_2]MAX_OUTPUT
setp   pid.z.error-previous-target true
setp   pid.z.maxerror 0.012700

net z-index-enable  =>  pid.z.index-enable
net z-enable        =>  pid.z.enable
net z-pos-cmd       =>  pid.z.command
net z-pos-fb        =>  pid.z.feedback
net z-output        <=  pid.z.output

# Step Gen signals/setup
setp   hm2_7i76e.0.stepgen.02.dirsetup        [JOINT_2]DIRSETUP
setp   hm2_7i76e.0.stepgen.02.dirhold         [JOINT_2]DIRHOLD
setp   hm2_7i76e.0.stepgen.02.steplen         [JOINT_2]STEPLEN
setp   hm2_7i76e.0.stepgen.02.stepspace       [JOINT_2]STEPSPACE
setp   hm2_7i76e.0.stepgen.02.position-scale  [JOINT_2]STEP_SCALE
setp   hm2_7i76e.0.stepgen.02.step_type        0
setp   hm2_7i76e.0.stepgen.02.control-type     1
setp   hm2_7i76e.0.stepgen.02.maxaccel         [JOINT_2]STEPGEN_MAXACCEL
setp   hm2_7i76e.0.stepgen.02.maxvel           [JOINT_2]STEPGEN_MAXVEL

# ---closedloop stepper signals---
net z-pos-cmd    <= joint.2.motor-pos-cmd
net z-vel-cmd    <= joint.2.vel-cmd
net z-output     => hm2_7i76e.0.stepgen.02.velocity-cmd
net z-pos-fb     <= hm2_7i76e.0.stepgen.02.position-fb
net z-pos-fb     => joint.2.motor-pos-fb
net z-enable     <= joint.2.amp-enable-out
net z-enable     => hm2_7i76e.0.stepgen.02.enable

# ---setup home / limit switch signals---
net z-home-sw     =>  joint.2.home-sw-in
net z-neg-limit     =>  joint.2.neg-lim-sw-in
net z-pos-limit     =>  joint.2.pos-lim-sw-in

#*******************
#  SPINDLE CONTROL - Jaspar custom
#*******************
net spindle-on    => hm2_7i76e.0.7i76.0.0.output-08
net spindle-cw    => hm2_7i76e.0.7i76.0.0.output-09
net spindle-on    <= spindle.0.on
net spindle-cw    <= spindle.0.forward
net spindle-ccw   <= spindle.0.reverse

#*******************
#  MPG HANDWHEEL - Jaspar custom
#*******************
# MPG encoder configuration
setp mpg-encoder.position-scale 4
setp mpg-encoder.x4-mode 0

# MPG encoder connections
net mpg-a    <= hm2_7i76e.0.7i76.0.0.input-16
net mpg-b    <= hm2_7i76e.0.7i76.0.0.input-17
net mpg-a    => mpg-encoder.phase-A
net mpg-b    => mpg-encoder.phase-B

# MPG axis selection
net mpg-axis-x   <= hm2_7i76e.0.7i76.0.0.input-21
net mpg-axis-z   <= hm2_7i76e.0.7i76.0.0.input-22

# MPG scale selection
net mpg-scale-x1   <= hm2_7i76e.0.7i76.0.0.input-19
net mpg-scale-x100 <= hm2_7i76e.0.7i76.0.0.input-20

# MPG scale selection logic
setp mpg-scale.gain 0.01
net mpg-scale-x1   => mpg-scale.enable
net mpg-scale-x100 => mpg-scale.enable

# MPG multiplexer configuration
setp mpg-mux.sel0 0
setp mpg-mux.sel1 0

# Connect axis selection to mux
net mpg-axis-x   => mpg-mux.sel0
net mpg-axis-z   => mpg-mux.sel1

# Connect MPG counts to mux inputs
net mpg-counts   <= mpg-encoder.counts
net mpg-counts   => mpg-mux.in0
net mpg-counts   => mpg-mux.in1
net mpg-counts   => mpg-mux.in2

# Connect mux outputs to halui jog
net mpg-x-jog    <= mpg-mux.out0
net mpg-y-jog    <= mpg-mux.out1  
net mpg-z-jog    <= mpg-mux.out2

net mpg-x-jog    => halui.axis.x.increment
net mpg-y-jog    => halui.axis.y.increment
net mpg-z-jog    => halui.axis.z.increment

#*******************
#  CONTROL BUTTONS - Jaspar custom
#*******************
# E-Stop
net estop-in     <= hm2_7i76e.0.7i76.0.0.input-18

# Program control
net program-start <= hm2_7i76e.0.7i76.0.0.input-25
net program-pause <= hm2_7i76e.0.7i76.0.0.input-26

# Connect program control to halui
net program-start => halui.program.run
net program-pause => halui.program.pause

#******************************
# connect miscellaneous signals
#******************************
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

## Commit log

2025-09-04 Conventions + Power connection
2025-09-04 mpg wiring ok I guess
2025-09-05 second config
    [jaspar2.hal]
2025-09-06 empty sample in up to date version
    [custom.hal, custom_gvcp.hal, custom_postgui.hal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]
2025-09-06 to test
    [jaspar_updated.hal]
2025-09-07 NO/NC estop fix
    [empty_sample_0.1.hal]
2025-09-08 mpg test
    [empty_sample.hal]
2025-09-08 test mpg
    [empty_sample.hal]
2025-09-08 lettuce pray
    [empty_sample.hal]
2025-09-08 crying rn
    [empty_sample.hal]
2025-09-08 pin change
2025-09-10 spindle working
    [empty_sample_0.3.hal]
2025-09-10 z brake
    [empty_sample_0.3.hal]
2025-09-11 mode 2 for mesa 7i76e
    [empty_sample.hal]
2025-09-11 mike's config
    [postgui_tormach_lathe.hal, tormach_lathe_mesa.hal]
2025-09-24 bkp jog ok
    [empty_sample_0.5.hal]
2025-09-25 install qtpyvcp probebasic
